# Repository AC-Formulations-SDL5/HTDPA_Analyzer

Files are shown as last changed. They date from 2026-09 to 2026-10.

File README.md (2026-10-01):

<p align="center">
  Self-Driving Laboratory, Acceleration Consortium, University of Toronto
</p>

<p align="center">
  HTDA demonstration
</p>

**[Open the full-resolution HTDA demonstration video](media/HTDA_demo.mp4)**

# HTDPA Analyzer

**Self-Driving Laboratory (SDL5) Formulation**  
**Acceleration Consortium - University of Toronto**

This repository contains the data, software, device designs, laboratory automation, and computational analyses supporting a scientific manuscript submitted to *Digital Discovery*. It is organized as a data-availability and reproducibility package for the high-throughput diffusion/permeation apparatus (HTDPA) and its self-driving laboratory workflow.

## Repository map

| Path | Contents |
| --- | --- |
| [`Example_data/`](Example_data/) | Raw example release datasets in Excel format for formulation and probe conditions. |
| [`Programming/OT_Protocol/`](Programming/OT_Protocol/) | Opentrons protocol used for automated sampling, media replacement, and lid handling. |
| [`Programming/OT_LabWare/`](Programming/OT_LabWare/) | Custom labware definitions used by the OT-2 workflow. |
| [`CAD_files/`](CAD_files/) | STL geometry for the HTDPA cell, reciprocating pump, holders, and related components. |
| [`UI/`](UI/) | Streamlit dashboard for release-profile QC, kinetic fitting, and manuscript summary figures. |
| [`HTDPA_RMSP_Files/`](HTDPA_RMSP_Files/) | RMSP Figure 2 and Figure S2 analyses, source data, generated figures, and post-equilibration validation workflow. |
| [`HTDA_Cell_CFD_Sim/`](HTDA_Cell_CFD_Sim/) | Transient Warp simulation, vorticity sweep, post-processing, notebook, and Ansys Workbench/Fluent files. |
| [`media/`](media/) | Repository presentation assets: quality-optimized and source GIFs, full-resolution video, and SDL5/Acceleration Consortium logo. |

## Reproducibility workflow

The repository is intended to preserve the path from physical design and automated experimentation to analysis and simulation:

1. **Device design:** Inspect the STL files in `CAD_files/` and the CFD/Workbench project in `HTDA_Cell_CFD_Sim/Workbench/`.
2. **Automated experiment:** Review the protocol and labware definitions in `Programming/` before loading a protocol onto an Opentrons system.
3. **Raw data:** Use the workbooks in `Example_data/` as the input data for release analysis. Preserve the original files when creating derived outputs.
4. **Analysis:** Run the dashboard in `UI/` to inspect release profiles, assay QC, kinetic models, apparent permeability, and the Korsmeyer-Peppas exponent.
5. **Flow simulation:** Follow [`HTDA_Cell_CFD_Sim/README.md`](HTDA_Cell_CFD_Sim/README.md) to reproduce the transient and steady-state design-supporting calculations.

## Release-analysis dashboard

The dashboard applies the publication-matched analysis rules documented in [`UI/README_HTDPA_dashboard.md`](UI/README_HTDPA_dashboard.md), including:

- strict-majority LOQ validation for quantitative time points;
- exclusion of negative cumulative-release values;
- common analysis windows for Zero-order, Higuchi, and First-order fits;
- optional start/end control for Korsmeyer-Peppas and Peppas-Sahlin fits;
- replicate-based CV reporting;
- six-panel summary output for release, variability, linearity, model fit, apparent `Kp`, and apparent `n`.

Install the dashboard dependencies and launch it from the dashboard directory:

```powershell
cd UI
python -m pip install -r requirements_htdpa_dashboard.txt
streamlit run htdpa_release_dashboard.py
```

The dashboard accepts the example Excel workbooks and can export analysis summaries as CSV and figures as high-resolution PNG files.

## CFD and flow-design analysis

<p align="center">
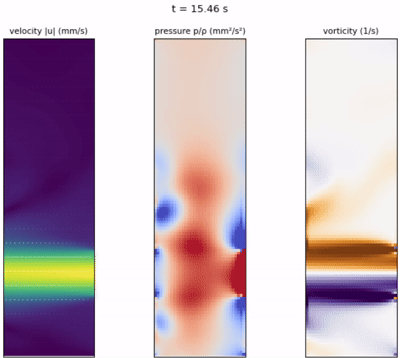
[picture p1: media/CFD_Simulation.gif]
CFD simulation of reciprocating flow
  
</p>

**[Open the CFD simulation video](media/CFD_Simulation.mp4)**

The CFD subproject includes a GPU-capable NVIDIA Warp implementation of a transient 2D reciprocating-flow model, a flow-rate sweep, post-processing scripts, a Jupyter notebook, cached numerical outputs, and an Ansys Workbench/Fluent 3D design study. The precomputed outputs are included so the results can be inspected without rerunning the simulations.

```powershell
cd HTDA_Cell_CFD_Sim
conda env create -f environment.yml
conda activate htda-cfd
python run_all.py
```

See [`HTDA_Cell_CFD_Sim/README.md`](HTDA_Cell_CFD_Sim/README.md) for model parameters, individual stages, hardware requirements, and limitations.

## Data availability and provenance

- Raw example workbooks are retained in `Example_data/`.
- RMSP source data, analysis scripts, figures, and validation outputs are retained in `HTDPA_RMSP_Files/`.
- Analysis and simulation scripts are retained alongside their cached outputs and notebooks.
- CAD and mesh/project files are retained in `CAD_files/` and `HTDA_Cell_CFD_Sim/Workbench/`.
- Protocol and labware definitions are retained in `Programming/`.
- The dashboard changelog is maintained in [`UI/CHANGELOG.md`](UI/CHANGELOG.md).
- Generated figures and exported summaries should be treated as derived data and should retain a clear link to their input workbook and analysis settings.

This repository is a research artifact for the associated manuscript. Experimental interpretation should use the manuscript and the documented analysis assumptions together with the files here. The CFD model is design-supporting and includes the limitations described in its subproject README; it is not a substitute for experimental validation.

## Citation

Please cite the associated *Digital Discovery* manuscript and identify the repository revision used for analysis. A formal citation record can be added here when the manuscript and repository release receive their final bibliographic information.

## Contact

**Self-Driving Laboratory (SDL5) Formulation**  
Acceleration Consortium  
University of Toronto

- Frantz Le Devedec (frantz.ledevedec@utoronto.ca)
- Mahdi Rastegardoost (m.rastegardoost@utoronto.ca)
- Zeqing Bao (zeqing.bao@utoronto.ca)

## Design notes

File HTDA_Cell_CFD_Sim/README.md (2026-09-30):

# HTDA Cell CFD Simulation

Supporting CFD files for the HTD/PA (high-throughput diffusion / permeation apparatus) receptor-cell design.

The folder has two parts:

1. **Transient 2D reciprocating-flow model (Python / NVIDIA Warp).** A single receptor cell (a rectangular chamber with inlet and outlet ports) is driven by the bipolar square-wave flow of the multichannel reciprocating pump. The model gives velocity, pressure and vorticity fields over one reciprocation cycle, plus peak and RMS vorticity as a function of flow-rate amplitude.
2. **Steady-state 3D design study (Ansys Workbench / Fluent 2025 R2).** This is the project used to compare candidate cell geometries (velocity contours, streamlines, pressure).

For the scientific background and how the results were used, see [Explanation.md](Explanation.md).

---

## Contents

| File / folder | Description |
|---|---|
| `warp_reciprocating_flow.py` | Solver: geometry, physics parameters, Taylor–Hood Q2–Q1 Navier–Stokes, `run()` (single flow rate) and `run_sweep()` (flow-rate sweep) |
| `plot_reciprocating_flow.py` | Post-processing: snapshot-grid figure and vorticity-vs-flow-rate figure |
| `build_artifact.py` | Builds the standalone interactive HTML frame viewer |
| `run_all.py` | **One-command runner** for all stages (simulation → sweep → figures → viewer) |
| `reciprocating_flow_CFD.ipynb` | Notebook version: explanation, run, and plots |
| `environment.yml` | Conda environment with the required libraries |
| `reciprocating_flow_results.npz` | *Output:* ~60 frames over one period at Q = 40 mL/min (u, p, vorticity) |
| `vorticity_sweep_results.npz` | *Output:* sweep of Q = 5–50 mL/min (peak/RMS vorticity, peak velocity, pressure, Re) |
| `snapshot_grid.png` | *Output:* velocity / pressure / vorticity at 4 key phases of the cycle |
| `vorticity_vs_flowrate.png` | *Output:* vorticity and vorticity/Q vs. flow-rate amplitude |
| `reciprocating_flow_viewer.html` | *Output:* self-contained interactive viewer (open in any browser) |
| `Workbench/` | Ansys Workbench project (`HTDA_Cell_Design.wbpj` + `_files/`: geometry, mesh, Fluent case/data, exported images) |

The precomputed outputs are included, so the figures and viewer can be inspected without rerunning anything.

---

## Requirements

- **Python 3.10 or 3.11** (tested with 3.11 and warp-lang 1.13.0)
- **NVIDIA GPU with a recent CUDA driver** (recommended). Warp also runs on the CPU if no GPU is found, but it is much slower.
- Libraries: `numpy`, `matplotlib`, `warp-lang`, and `jupyterlab`/`ipykernel` for the notebook (all listed in [environment.yml](environment.yml))
- *Optional:* Ansys Workbench 2025 R2 or newer to open the `Workbench/` project

## Installation

With conda (recommended):

```bash
conda env create -f environment.yml
conda activate htda-cfd
```

With pip only:

```bash
pip install numpy matplotlib warp-lang jupyterlab ipykernel
```

To check the install (prints the CUDA device Warp found):

```bash
python -c "import warp as wp; wp.init()"
```

---

## Running

Run every command from inside this folder, because outputs are written next to the scripts.

### Option A: one command

```bash
python run_all.py                    # reuse cached .npz files, regenerate figures + viewer
python run_all.py --force            # rerun both simulations from scratch
```

Individual stages:

```bash
python run_all.py --stage sim        --force --q 40     # single transient run at Q = 40 mL/min
python run_all.py --stage sweep      --force --q-min 5 --q-max 50 --n-q 10
python run_all.py --stage figures                       # PNG figures from the .npz files
python run_all.py --stage viewer                        # interactive HTML viewer
```

Approximate runtimes on a laptop RTX GPU: single run ~2 min; sweep (10 flow rates) ~15–20 min.

### Option B: notebook

Open `reciprocating_flow_CFD.ipynb` in Jupyter or VS Code, select the `htda-cfd` kernel, and run all cells. The notebook uses the cached `.npz` files if they exist. Delete them to force a new simulation.

### Option C: individual scripts

```bash
python warp_reciprocating_flow.py    # single run -> reciprocating_flow_results.npz
python plot_reciprocating_flow.py    # figures (needs both .npz files)
python build_artifact.py             # interactive HTML viewer
```

---

## Model summary

| Parameter | Value | Variable in `warp_reciprocating_flow.py` |
|---|---|---|
| Chamber (W × H) | 7.75 × 27 mm | `RECT_W`, `RECT_H` |
| Port diameter | 4 mm, centred 7 mm above the chamber floor | `PIPE_D`, `Y_C` |
| Inlet stub length | 12 mm (3 × D, keeps the boundary condition away from the junction) | `STUB_LEN` |
| Through-plane depth (2D → flow-rate conversion) | 4 mm | `DEPTH` |
| Fluid | water, ν = 1.0 mm²/s | `NU` |
| Flow forcing | bipolar square wave, amplitude 40 mL/min, period 9 s | `Q_AMP_ML_MIN`, `PERIOD` |
| Grid / time step | 130 × 112 cells (masked `Grid2D`), Δt = 0.009 s | `NX`, `NY`, `DT` |
| Simulated duration | 2 periods; statistics and frames are taken from the 2nd period | `N_PERIODS` |

- **Units:** mm and s throughout. Pressure is kinematic (p/ρ, mm²/s²). Multiply by ρ = 1000 kg/m³ and by 10⁻⁶ to get Pa.
- **Method:** Taylor–Hood Q2/Q1 elements, implicit viscosity, semi-Lagrangian advection, hard velocity-Dirichlet BCs (parabolic profile at the two port tips, no-slip elsewhere), preconditioned CG saddle-point solve.
- **Sweep statistics:** the sweep excludes samples within 15 % of each flow reversal, so the reported vorticity reflects the fully developed flow and not the reversal transient.
- **Changing the device:** edit the constants at the top of `warp_reciprocating_flow.py`, then run `python run_all.py --force`. Velocity, pressure and vorticity magnitudes scale roughly as 1/`DEPTH`.

## Limitations

This is a simplified 2D planar idealization, and the results are design-supporting predictions. They have not been validated experimentally. The square-wave forcing is instantaneous, so it produces a real, sharp inertial pressure transient at each reversal; this is not a numerical artifact.

## Ansys Workbench project

Open `Workbench/HTDA_Cell_Design.wbpj` in Ansys Workbench 2025 R2 or newer, and keep the `HTDA_Cell_Design_files/` folder next to it. Exported contour, streamline and vector images are in `Workbench/HTDA_Cell_Design_files/user_files/`.

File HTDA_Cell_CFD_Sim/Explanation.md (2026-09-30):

## 2.1 HTD/PA design
The HTD/PA was designed as a modular, automation-compatible flow-cell platform for standardized diffusion/permeation experiments (Fig. 2C). The flow-cell module was designed in Fusion 360 (Autodesk, USA) and fabricated using transparent photopolymer resin (Clear Resin V4.1, Formlabs) on a Form 3L stereolithography printer. The transparent construction enables direct visualization of liquid circulation, bubble formation, membrane positioning, and receptor-chamber filling during operation. Each HTD/PA module consists of 4-pairs of dual flow-cells, with each cell set comprising a donor compartment accommodating an interchangeable commercial permeable insert (donor - sample) and a receptor compartment, connected to a closed-loop circulation system. Standard Luer-lock connectors were incorporated at the inlet and outlet ports of each channels to facilitate connection to silicone tubing, a customed inline heat exchanger, flow sensors, and a multichannel reciprocating pump (Section 2.2). The modular architecture enables replacement of donor inserts with different geometry while maintaining a standardized receptor geometry (Flow cell I.D 2.5 cm) across experiments (Fig. 2D). A custom 3D-printed lid secures the donor inserts, minimizes dead volume above the receptor chamber, and reduce evaporation during long-term experiments. A self-sealing cross-slit silicone septum integrated into the lid allows repeated robotic pipette access for automated release sampling without exposing the receptor compartment to the environment. The HTD/PA cell geometry and mechanical design were evaluated through computational fluid dynamics to identify a design that achieves adequate receptor-side mixing across all cells of the apparatus. Steady-state CFD velocity contours of flow through the HTD/PA block cells (Ansys Fluent 2025 R2; Fig. 2E) were used to compare candidate cell geometries and select an optimized design. For the optimized cell, shear rate and vorticity were evaluated as a function of inlet flow rate (Fig. 2F); both increased with flow rate, with vorticity rising from ~3.2 s⁻¹ at 10 mL/min to ~16 s⁻¹ at 40 mL/min. As a measure of local shear and rotational flow intensity, vorticity was adopted as a practical, quantitative proxy for convective mixing within the receptor chamber. Because the multichannel reciprocating pump (Section 2.2) delivers a bipolar square-wave flow-rate waveform rather than steady unidirectional flow, mixing under this operating condition was further assessed with a transient, simplified 2D model of a single receptor cell (a rectangular chamber with inlet/outlet ports positioned as in the cup-shaped receptor geometry, with the membrane and donor compartment above), solved in Python with the NVIDIA Warp finite-element framework by imposing the bipolar flow-rate waveform at the two ports. Figure 2G shows the resulting vorticity and pressure contours at representative time points across a reciprocation cycle, capturing jet formation, flow reversal, and the associated shear layers. Peak vorticity normalized by flow-rate amplitude (Fig. 2H) rises sharply between 5 and ~20 mL/min before plateauing at higher amplitudes, indicating diminishing mixing gains beyond this threshold; this relationship was used to set the minimum pump flow-rate amplitude required for adequate receptor-side mixing without operating at unnecessarily high flow. As with the steady-state Ansys analysis, these results were used as design-supporting predictions rather than an experimentally validated description of the hydrodynamic environment.

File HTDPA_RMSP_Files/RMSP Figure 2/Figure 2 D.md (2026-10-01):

# SLF3X peak-to-peak flow versus RPM

Generate the figure with the standalone [Python script](SLF3X_peak_to_peak_vs_RPM.py).

Peak-to-peak flow versus pump speed

## Installation

Requires Python 3.9 or newer, NumPy, pandas, and Matplotlib:

```bash
python3 -m pip install numpy pandas matplotlib
```

## Input files

Place these CSV files beside the script:

| Pump speed (RPM) | Source file |
| ---: | --- |
| 5 | `HTDPA_5RPM_30oC_1H.csv` |
| 10 | `HTDPA_10RPM_30oC_1H.csv` |
| 15 | `HTDPA_15RPM_30oC_1H.csv` |
| 20 | `HTDPA_20RPM_30oC_1H.csv` |
| 25 | `HTDPA_25rpm_30oC_1H.csv` |
| 30 | `HTDPA_30rpm_30oC_1.5H.csv` |

The script reads numeric flow columns `s1_flow_ml_min` through `s4_flow_ml_min`. At 30 RPM, sensor 2 is excluded because of the sensor issue documented in the combined-figure script; its column is unused. The source data contain one-second averaged readings. No Excel workbooks, backup files, existing images, or other project scripts are needed.

## Usage

From the script folder:

```bash
python3 SLF3X_peak_to_peak_vs_RPM.py
```

The output is `SLF3X_peak_to_peak_vs_RPM.png`, saved beside the script. Running the default command overwrites an existing image with that name. Source CSV files are unchanged.

To specify other locations:

```bash
python3 SLF3X_peak_to_peak_vs_RPM.py --data-dir "/path/to/data" --output "/path/to/figure.png"
```

The output directory must already exist. Show command-line help with:

```bash
python3 SLF3X_peak_to_peak_vs_RPM.py --help
```

## Calculations

### Flow recalibration

Each recorded flow value is corrected as follows:

```text
corrected flow = recorded flow / old embedded factor × gravimetric factor
```

| Sensor | Old embedded factor | Gravimetric factor |
| --- | ---: | ---: |
| S1 | 4.4 | 4.508343 |
| S2 | 4.2 | 4.474666 |
| S3 | 2.0 | 2.320488 |
| S4 | 3.0 | 3.340179 |

These constants assume the calibration basis of the supplied CSV files. Using already recalibrated values would apply the correction again.

### Plateau detection

For each sensor, the deadband is 15% of the 90th percentile of absolute finite flow values. Contiguous positive and negative runs outside that deadband must contain at least three samples.

A positive lobe plateau is the mean of values at or above that lobe's median. A negative lobe plateau is the mean of values at or below its median. Q+ and Q− are the respective means across detected lobe plateaus.

### Peak-to-peak flow and error bars

Each sensor's peak-to-peak flow is **Q+ − Q−**, in mL/min. It is a plateau-based measure, rather than the raw maximum minus minimum.

Each bar is the mean across four sensors at 5–25 RPM, and three sensors (S1, S3, S4) at 30 RPM. Error bars show ±1 sample standard deviation across sensors (`ddof=1`). Labels show the mean and coefficient of variation:

```text
CV (%) = 100 × sample SD / |mean|
```

## Output and validation

The output is a 19,200 × 10,800 pixel PNG rendered at 1200 DPI (16 × 9 inches). The script generates only the peak-to-peak figure.

The original 300 DPI version was checked against the existing figure using the supplied CSV files and reproduced it pixel for pixel. The script now renders the same plot at 1200 DPI. Different Matplotlib versions or fonts may affect rendering.

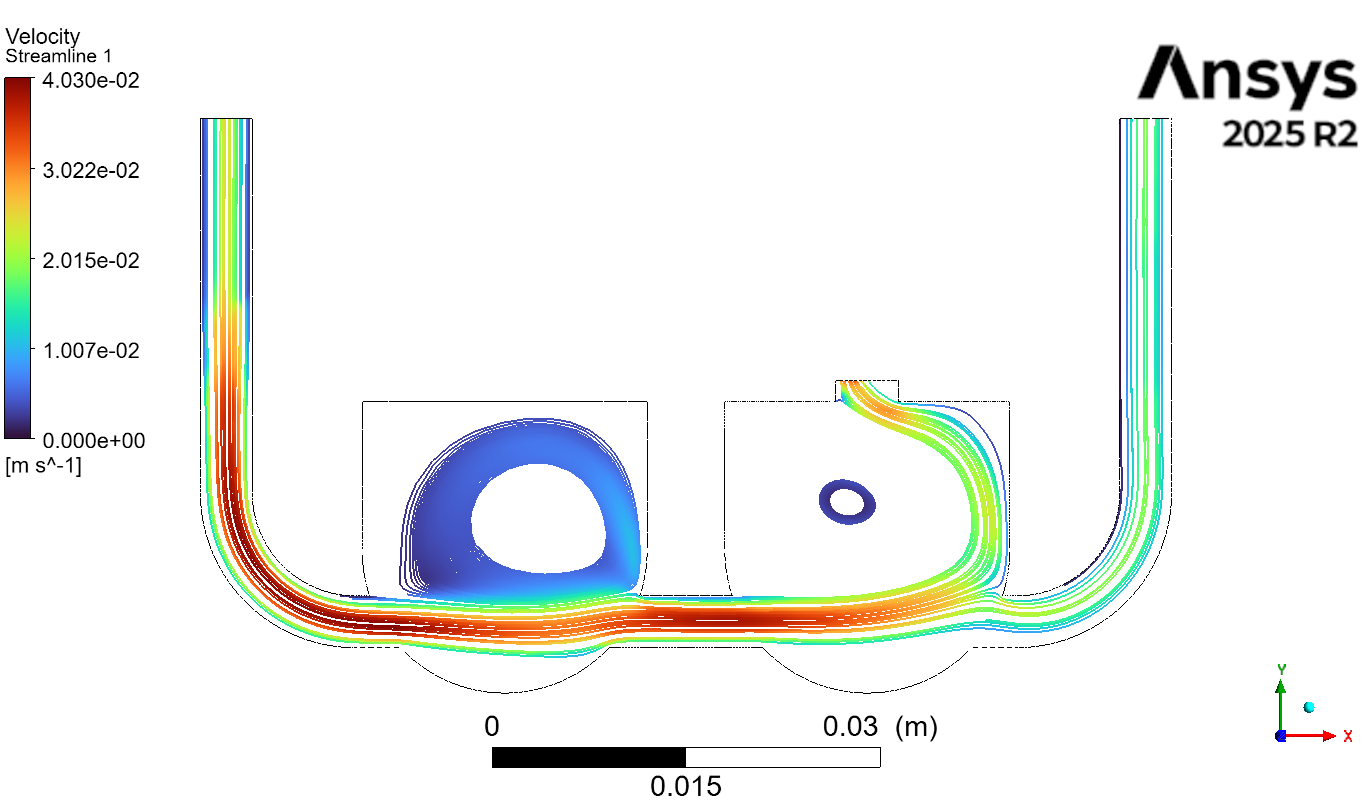
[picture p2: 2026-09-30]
HTDA_Cell_CFD_Sim/Workbench/HTDA_Cell_Design_files/user_files/HTDA_Cell_Design_streamline2.png

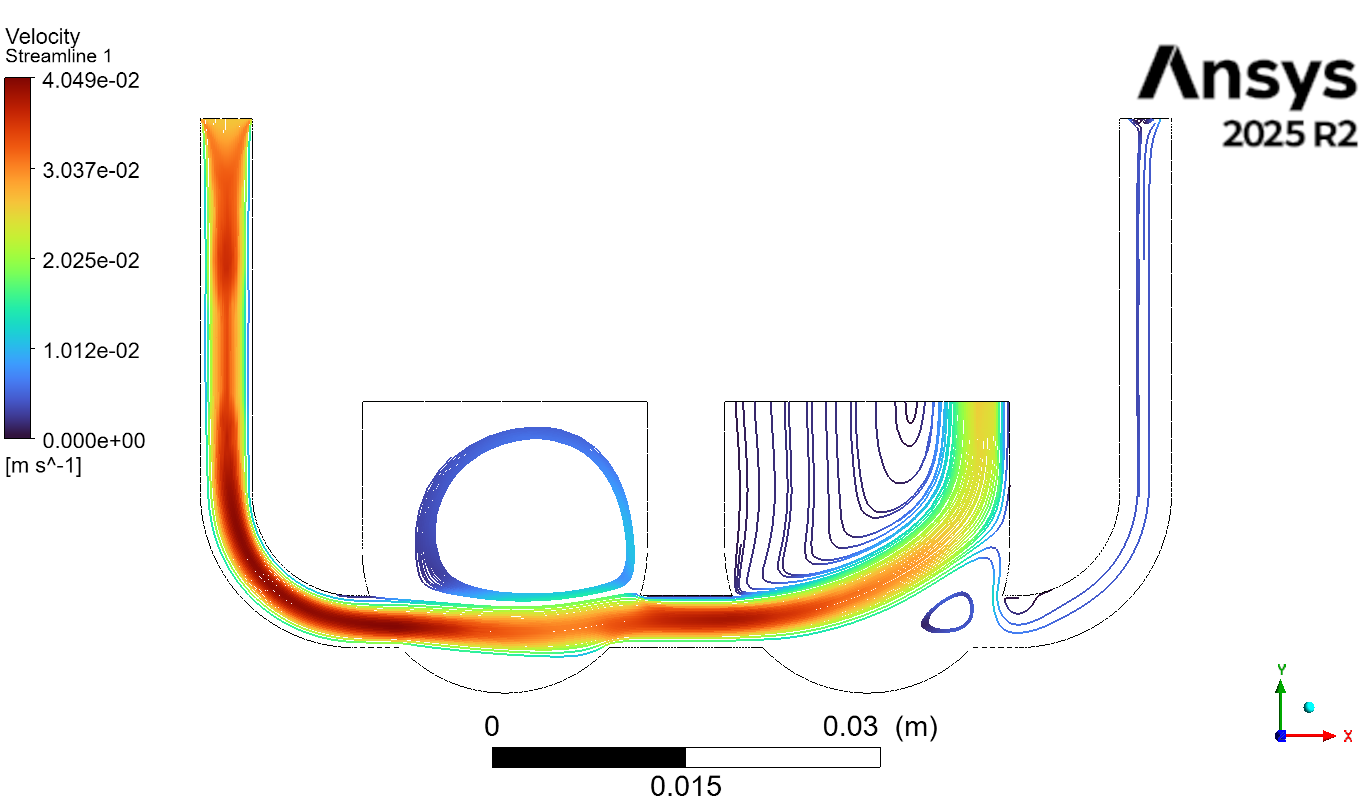
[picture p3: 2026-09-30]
HTDA_Cell_CFD_Sim/Workbench/HTDA_Cell_Design_files/user_files/HTDA_Cell_Design_streamline.png

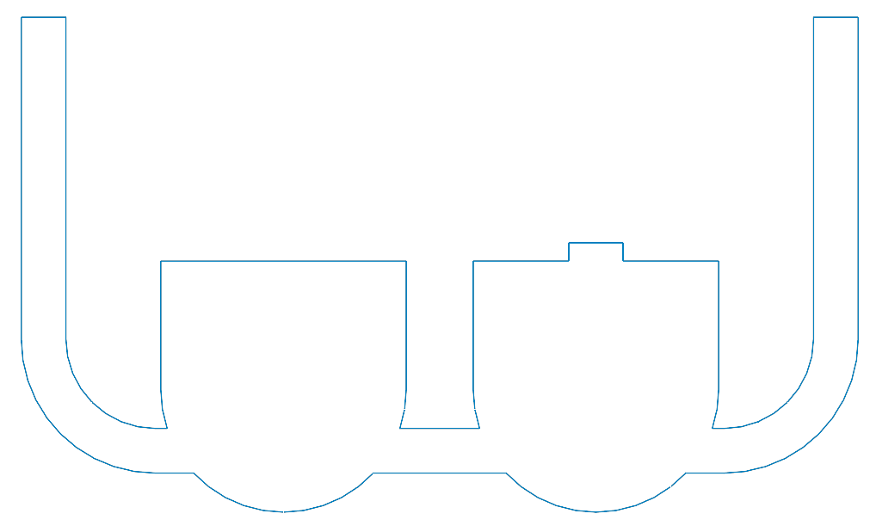
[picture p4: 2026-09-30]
HTDA_Cell_CFD_Sim/Workbench/HTDA_Cell_Design_files/user_files/geometry_2d.png

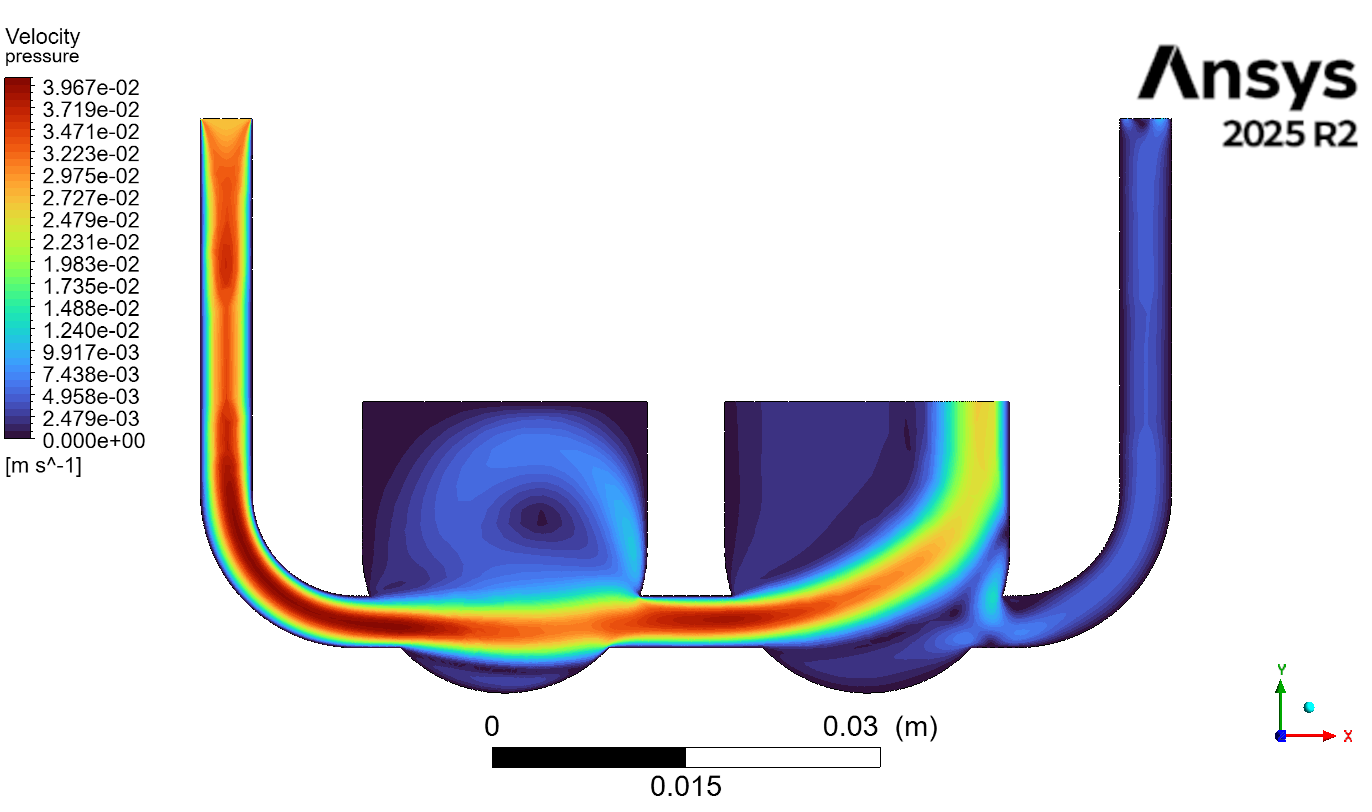
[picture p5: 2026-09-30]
HTDA_Cell_CFD_Sim/Workbench/HTDA_Cell_Design_files/user_files/HTDA_Cell_Design_velocity.png

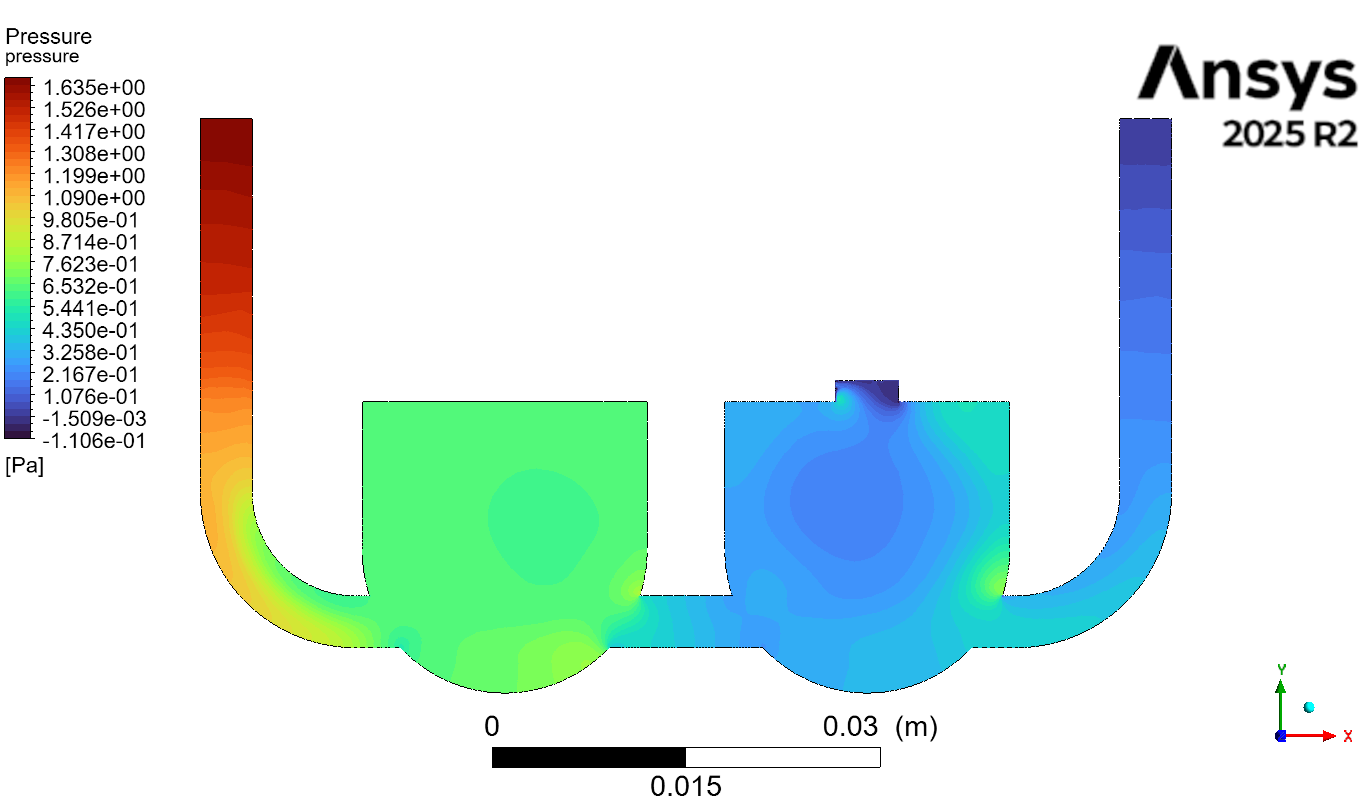
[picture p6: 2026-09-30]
HTDA_Cell_CFD_Sim/Workbench/HTDA_Cell_Design_files/user_files/HTDA_Cell_Design_pressure2.png

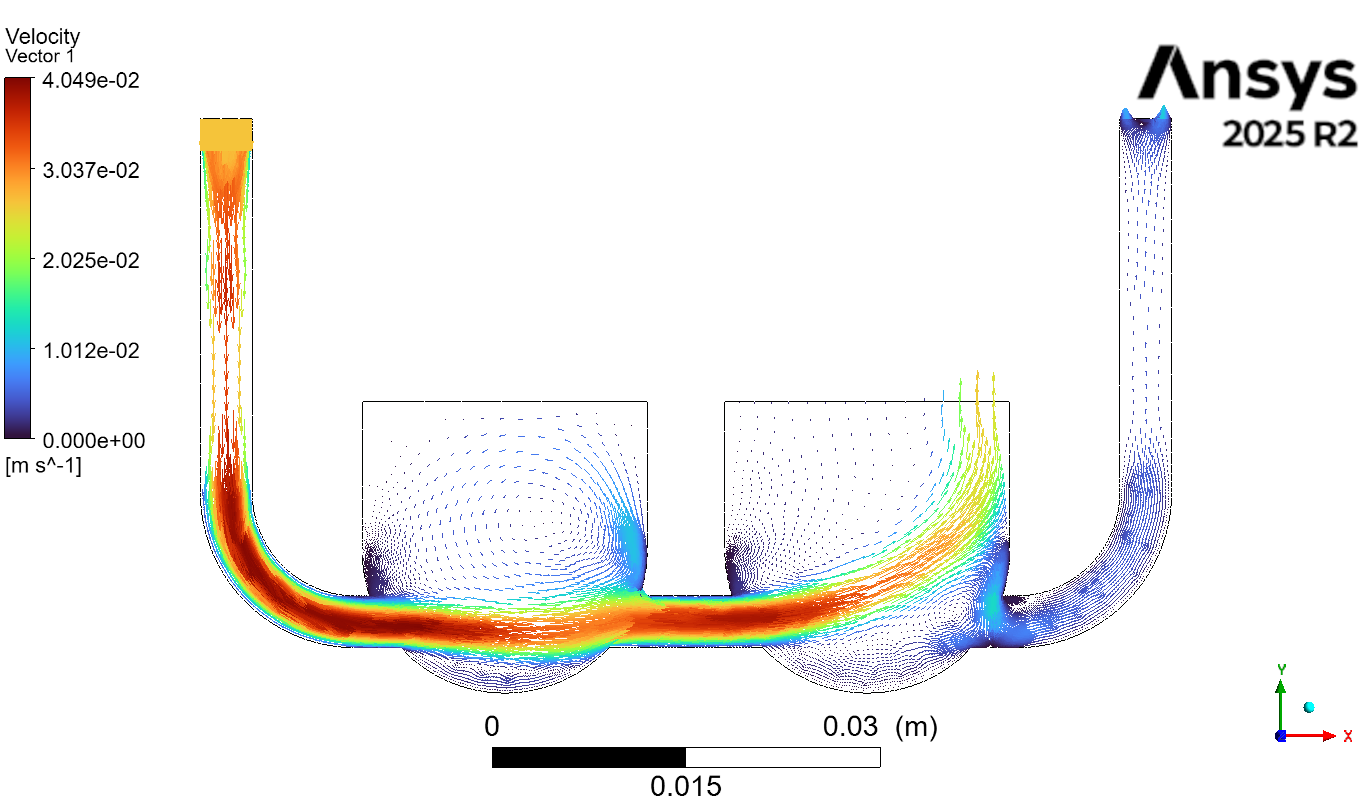
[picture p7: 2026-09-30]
HTDA_Cell_CFD_Sim/Workbench/HTDA_Cell_Design_files/user_files/HTDA_Cell_Design_vector.png

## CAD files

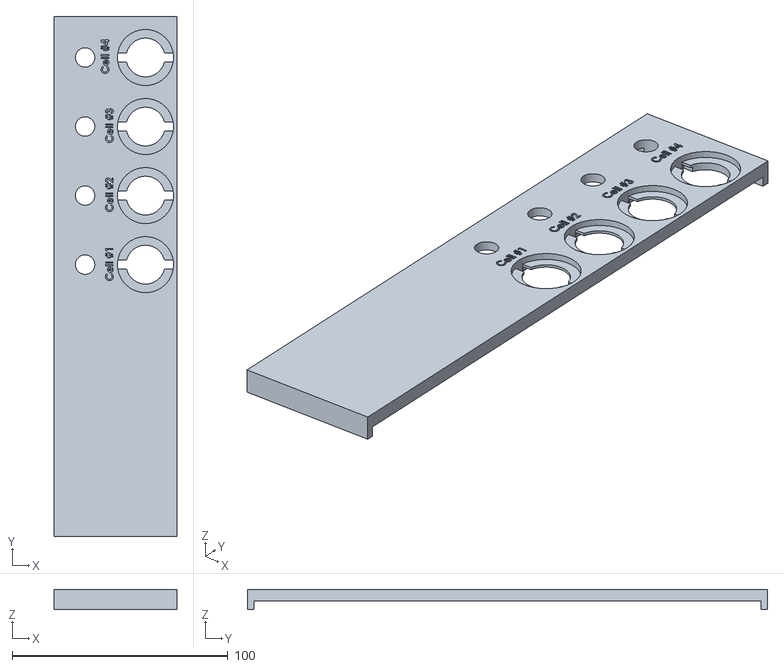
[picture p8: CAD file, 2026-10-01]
CAD_files/HTDPA_Lid.STL
56.8 x 241.0 x 9.50

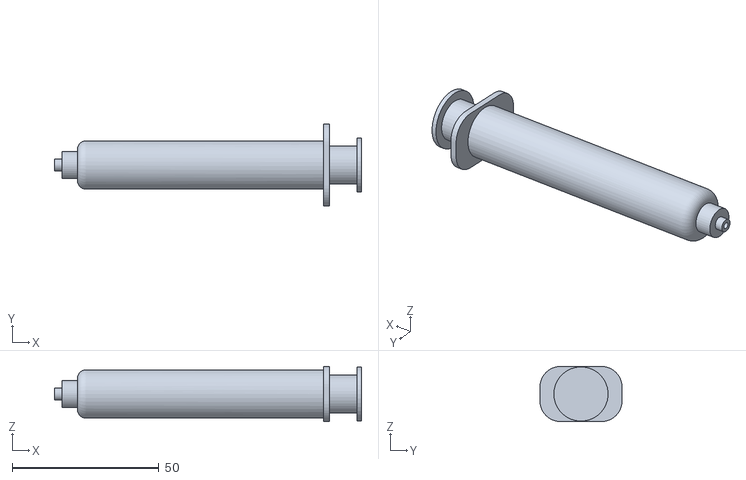
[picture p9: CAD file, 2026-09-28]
CAD_files/RMSP - OT-2 Reference Model Updated-1 Stripped __Model-1 Reciprocating PUmp-1 Pump_v3-2-1.STL
104.7 x 28.0 x 18.8

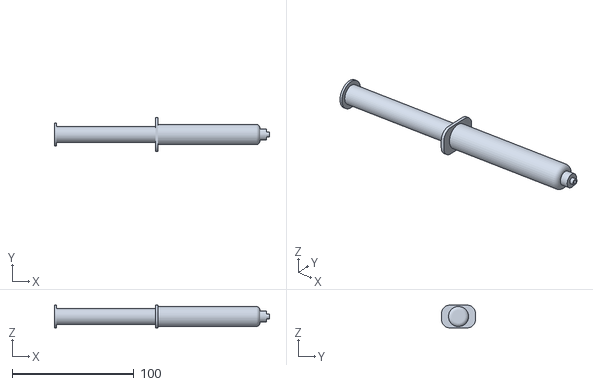
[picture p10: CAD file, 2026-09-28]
CAD_files/RMSP - OT-2 Reference Model Updated-1 Stripped __Model-1 Reciprocating PUmp-1 Pump_v3-8-1.STL
176.7 x 28.0 x 18.8

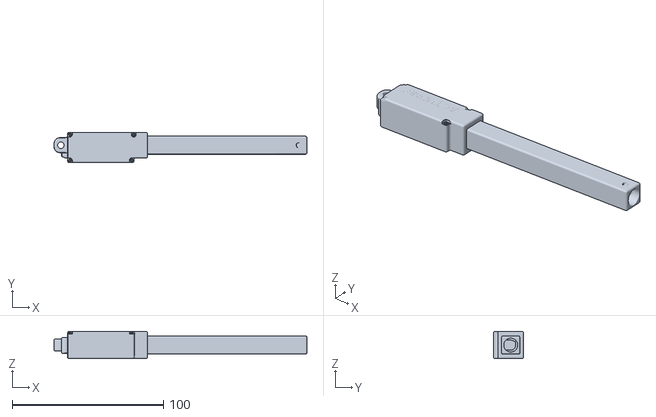
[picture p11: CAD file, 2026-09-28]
CAD_files/RMSP - OT-2 Reference Model Updated-1 Stripped __ng PUmp-1 l16_100mm-1 L16_100MM_BODY_A-1.STL
167.4 x 20.0 x 18.1

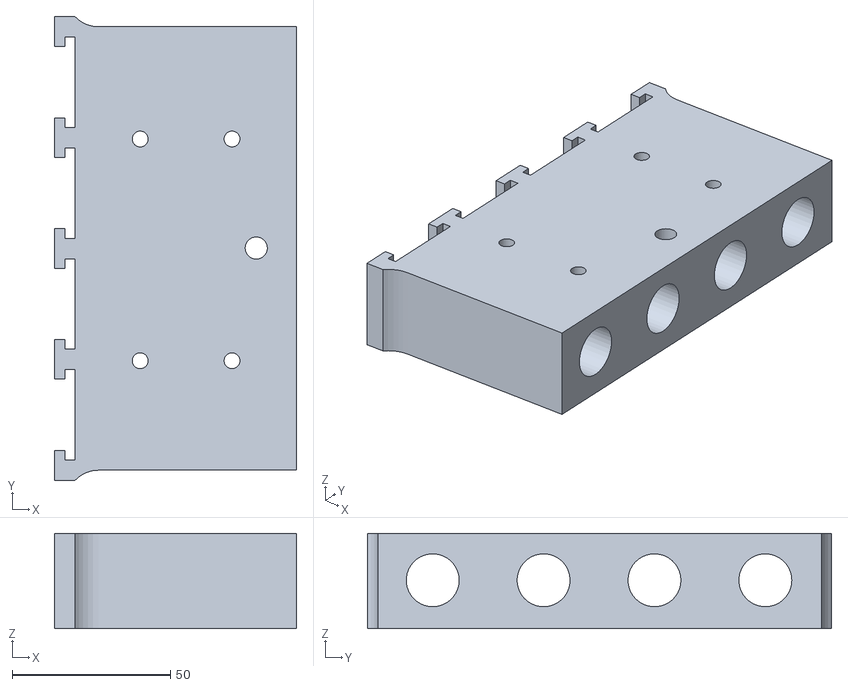
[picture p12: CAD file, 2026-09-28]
CAD_files/RMSP - OT-2 Reference Model Updated-1 Stripped __odel-1 Reciprocating PUmp-1 Pump_v3-10-1.STL
76.5 x 146.5 x 30.0

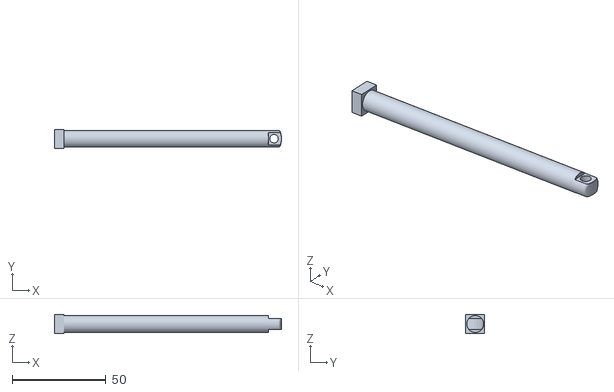
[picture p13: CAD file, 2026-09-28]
CAD_files/RMSP - OT-2 Reference Model Updated-1 Stripped __ng PUmp-1 l16_100mm-1 L16_100MM_LIFT_A-1.STL
121.0 x 9.90 x 10.2

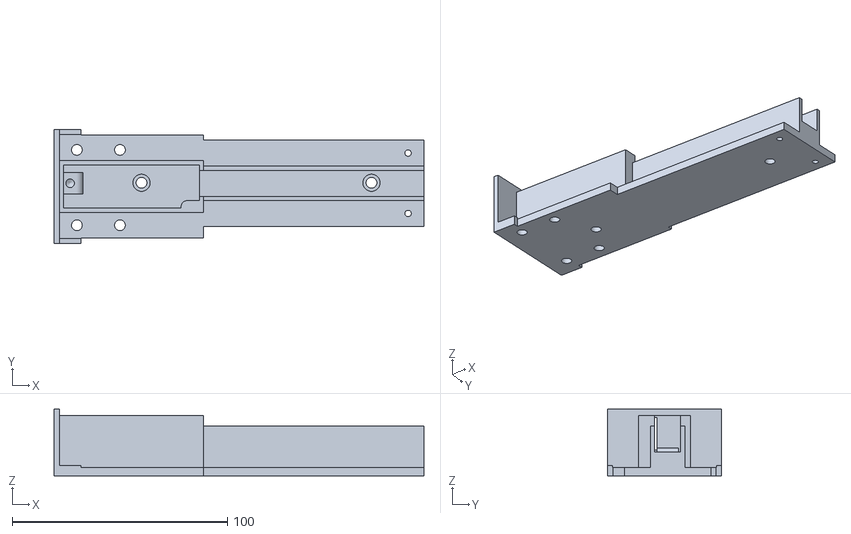
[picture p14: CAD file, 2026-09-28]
CAD_files/RMSP - OT-2 Reference Model Updated-1 Stripped __-1 Reciprocating PUmp-1 Act_housing_V2-1.STL
171.9 x 53.0 x 31.0

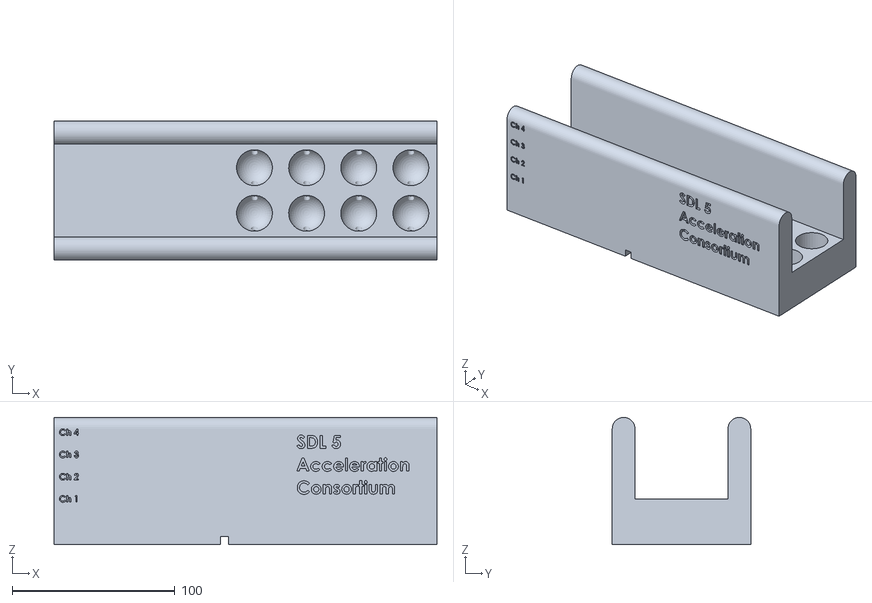
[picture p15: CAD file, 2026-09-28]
CAD_files/HTDA_4C.STL
235.0 x 85.0 x 78.0

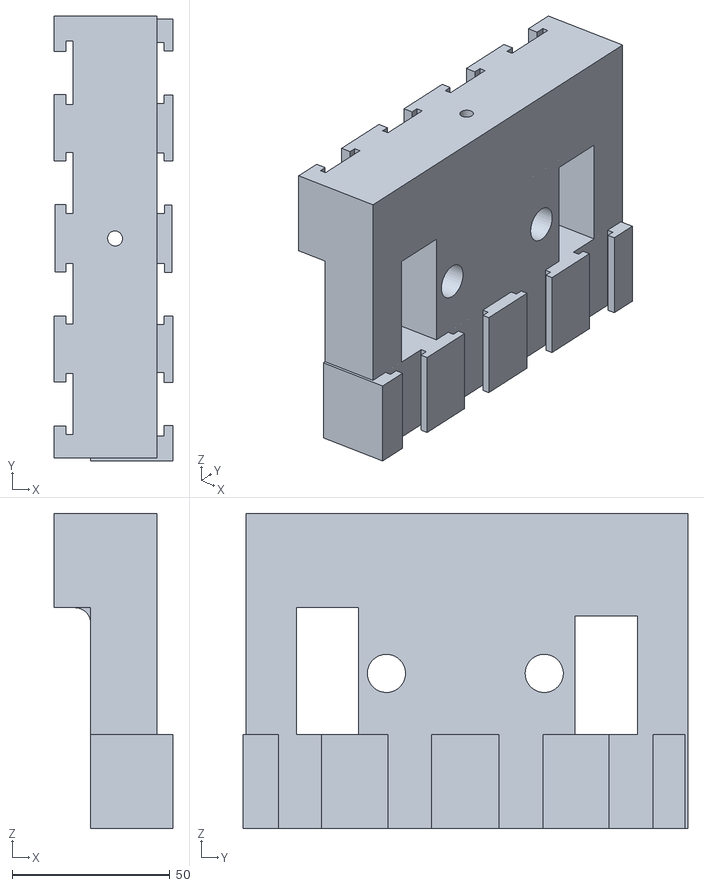
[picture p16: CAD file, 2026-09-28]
CAD_files/RMSP - OT-2 Reference Model Updated-1 Stripped __Model-1 Reciprocating PUmp-1 Pump_v3-9-1.STL
37.6 x 141.0 x 99.9

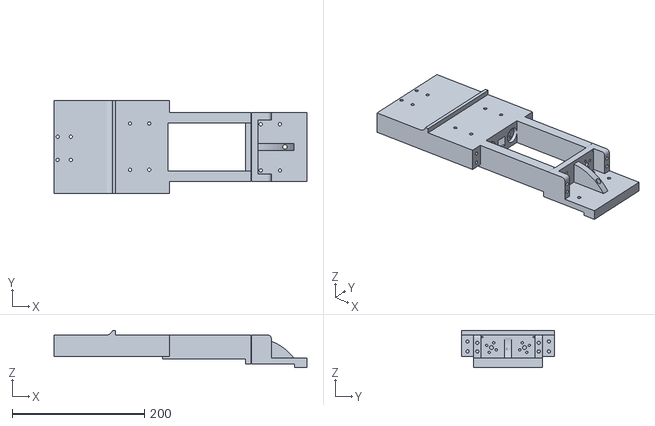
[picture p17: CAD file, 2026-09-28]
CAD_files/RMSP - OT-2 Reference Model Updated-1 Stripped __se_plus_holder_V2-1 Syringe_housing_V2-1.STL
382.8 x 140.1 x 56.0

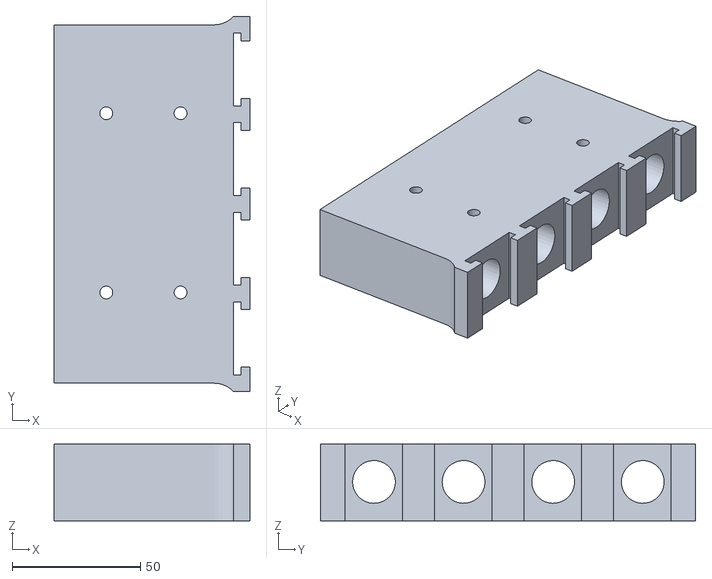
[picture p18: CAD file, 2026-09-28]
CAD_files/RMSP - OT-2 Reference Model Updated-1 Stripped __Model-1 Reciprocating PUmp-1 Pump_v3-5-1.STL
76.5 x 146.5 x 30.0

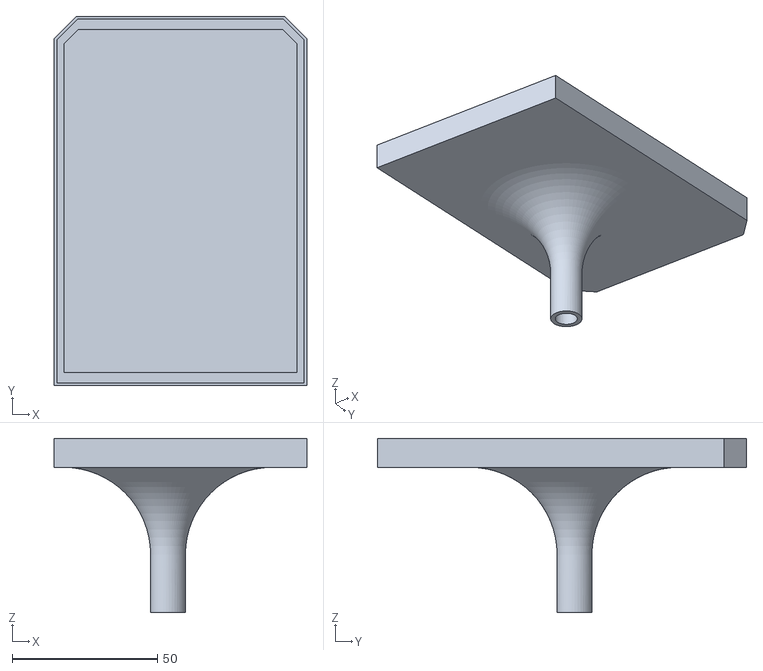
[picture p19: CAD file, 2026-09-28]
CAD_files/wellplate_lid.STL
87.0 x 127.0 x 60.0

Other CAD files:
CAD_files/RMSP - OT-2 Reference Model Updated-1 Stripped __Model-1 Reciprocating PUmp-1 Pump_v3-1-1.STL
CAD_files/RMSP - OT-2 Reference Model Updated-1 Stripped __Model-1 Reciprocating PUmp-1 Pump_v3-0-1.STL
CAD_files/RMSP - OT-2 Reference Model Updated-1 Stripped __Model-1 Reciprocating PUmp-1 Pump_v3-4-1.STL
CAD_files/RMSP - OT-2 Reference Model Updated-1 Stripped __Model-1 Reciprocating PUmp-1 Pump_v3-7-1.STL
CAD_files/RMSP - OT-2 Reference Model Updated-1 Stripped __Model-1 Reciprocating PUmp-1 Pump_v3-3-1.STL
CAD_files/RMSP - OT-2 Reference Model Updated-1 Stripped __Model-1 Reciprocating PUmp-1 Pump_v3-6-1.STL

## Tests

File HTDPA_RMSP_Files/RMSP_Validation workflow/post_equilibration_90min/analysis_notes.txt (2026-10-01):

Post-equilibration descriptive statistics
Source: 20260916_1um_MBP23_30rpm_CH1_CH3_CH4_corrected.csv
Window: elapsed time >=90 min, relative to first recorded timestamp.
Actual selected range: 90.002650–436.082117 min.
Samples per channel: 20761. Channels: CH1, CH3, CH4; CH2 is absent.
Data are already corrected; no additional correction factors applied.
No missing entries; timestamps strictly increasing. Maximum sampling interval: 1.057 s.
90 minutes is a user-selected cutoff, not a fitted or verified equilibration time.

Cycle detection: negative-to-positive transitions with hysteresis at 20% of
median nonzero absolute flow (thresholds in mL/min: {'CH1': np.float64(8.008000000000001), 'CH3': np.float64(8.76), 'CH4': np.float64(8.65)}).
Each cycle extends from one positive threshold crossing to the next.
Only fully bounded cycles starting >=90 min are included. Leading/trailing
partial cycles are excluded. At least 3 samples per polarity are required.
Q+ = mean of upper half (>=median) of positive phase samples above threshold.
Q− = mean of lower half (<=median) of negative phase samples below -threshold.
P–P = Q+ − Q−; symmetry = Q+/|Q−|, calculated per cycle before summarizing.
This explicit plateau estimator is comparable in concept to the S2 upper/lower
half method but uses hysteresis to avoid transition noise.
Upper/lower decile estimates are also supplied, matching the decile concept
in the existing plotting script. Its imported helper is absent, so exact
reproduction of its unpublished cycle algorithm is not claimed.
Raw peak-to-peak = per-cycle max minus min; distinct from plateau P–P.
Volumes integrate clipped positive/negative flow over each cycle with the
trapezoidal rule; pull volume is a positive magnitude.

SD is sample SD (ddof=1); CV=100*SD/abs(mean). Temperature CV uses Celsius,
matching the prior figure; this CV depends on the temperature scale.
Temperature/sample-flow statistics use every selected sample, including
transitions. Flow waveform SD/CV is distinct from cycle-to-cycle plateau CV;
signed-flow CV can be large because its mean is near zero.
Inter-channel statistics use the three channel means (n=3), not pooled samples.
Temperature differences use paired simultaneous samples.
30-minute windows assign cycles by cycle start, with a shorter final window.
No inter-day CV is available from this single recording. Repeated time samples
and cycles are not independent biological/experimental replicates; no naive
confidence intervals or significance tests are reported.

Channel summary:
channel  n_samples  n_cycles  temperature_mean_C  temperature_sd_C  temperature_cv_percent  Q_plus_mean  Q_plus_sd  Q_plus_cv_percent  Q_minus_mean  Q_minus_sd  Q_minus_cv_percent  P_to_P_mean  P_to_P_sd  P_to_P_cv_percent  symmetry_mean  symmetry_sd  symmetry_cv_percent  period_s_mean  period_s_sd  period_s_cv_percent
    CH1      20761       848             29.1045            0.6349                  2.1814      40.4458     1.2396             3.0648      -42.7489      0.6363              1.4884      83.1947     1.6356             1.9659         0.9461       0.0258               2.7254        24.4526       0.4972               2.0332
    CH3      20761       848             28.2498            0.5802                  2.0537      43.8108     0.5403             1.2333      -49.9699      0.5801              1.1608      93.7807     1.0906             1.1629         0.8767       0.0048               0.5518        24.4526       0.4972               2.0332
    CH4      20761       848             27.2620            0.5141                  1.8857      43.3686     0.9165             2.1132      -46.2191      0.7579              1.6398      89.5877     1.6483             1.8399         0.9383       0.0075               0.7992        24.4526       0.4979               2.0362

Temperature differences:
comparison unit     n   mean     sd  cv_percent  median    min    q25    q75    max
 CH1 − CH3   °C 20761 0.8547 0.1425     16.6741  0.8000 0.3000 0.7000 1.0000 1.3000
 CH1 − CH4   °C 20761 1.8425 0.1923     10.4385  1.8000 1.4000 1.7000 2.0000 2.4000
 CH3 − CH4   °C 20761 0.9878 0.1045     10.5838  1.0000 0.7000 0.9000 1.1000 1.5000

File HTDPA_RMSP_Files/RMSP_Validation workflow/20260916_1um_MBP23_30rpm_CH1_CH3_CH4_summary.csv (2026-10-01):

channel | correction_factor | n_cycles | q_plus_mean | q_plus_sd | q_plus_cv_pct | q_minus_mean | q_minus_sd | q_minus_cv_pct | p_to_p_mean | q_ratio_mean | temperature_mean_c | temperature_sd_c | temperature_cv_pct
CH1 | 2.2 | 1892 | 41.06643210235534 | 1.9360607921485002 | 4.714460675139729 | -43.131548556430445 | 1.202631268902662 | 2.78828678578331 | 84.19798065878578 | 0.9521205121728185 | 29.136571675302246 | 0.6397711532963468 | 2.1957667512360484
CH3 | 2.0 | 1892 | 44.192074882995314 | 0.808460008227152 | 1.829423059151811 | -50.20121808386039 | 0.8256538214575876 | 1.6446888202560048 | 94.39329296685571 | 0.8802988566766071 | 28.273298791019002 | 0.5809766918785636 | 2.0548599446171116
CH4 | 2.5 | 1892 | 43.945380680108336 | 1.387984539434684 | 3.1584310295051066 | -46.55218471733278 | 1.0691064968378068 | 2.296576419193805 | 90.49756539744112 | 0.9440025413833295 | 27.285539723661483 | 0.5154434068565082 | 1.88907169173394

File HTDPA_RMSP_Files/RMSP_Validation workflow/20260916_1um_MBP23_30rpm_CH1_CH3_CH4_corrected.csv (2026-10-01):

time_s | s1_flow_ml_min | s1_temp_c | s3_flow_ml_min | s3_temp_c | s4_flow_ml_min | s4_temp_c
0.005 | 0.0 | 24.8 | 0.0 | 24.3 | 0.0 | 23.6
1.005 | 0.0 | 24.9 | 0.0 | 24.4 | 0.0 | 23.6
2.005 | 0.0 | 24.9 | 0.0 | 24.5 | 0.0 | 23.7
3.005 | 0.0 | 25.0 | 0.0 | 24.5 | 0.0 | 23.7
4.005 | 0.44000000000000006 | 24.9 | 0.0 | 24.5 | 0.0 | 23.7
5.036 | 0.66 | 24.5 | 1.8 | 24.3 | 1.75 | 23.5
6.036 | 23.1 | 23.6 | 25.0 | 22.8 | 29.0 | 22.2
7.036 | 52.58 | 21.7 | 53.4 | 21.3 | 53.5 | 21.1
8.036 | 49.50000000000001 | 21.4 | 50.6 | 21.0 | 51.25 | 20.9
9.036 | 49.06 | 21.5 | 49.6 | 20.9 | 50.5 | 20.8
10.037 | 49.06 | 21.8 | 49.8 | 20.9 | 51.0 | 20.7
11.037 | 48.84 | 21.9 | 49.0 | 21.0 | 52.5 | 20.7
12.037 | 49.50000000000001 | 22.0 | 49.8 | 21.1 | 51.25 | 20.8
13.037 | 48.84 | 22.1 | 49.0 | 21.2 | 50.25 | 20.9
14.037 | 47.08 | 22.2 | 48.8 | 21.2 | 50.25 | 20.9
15.037 | 9.9 | 22.6 | 12.6 | 21.5 | 13.25 | 21.1
16.037 | -0.22000000000000003 | 23.2 | 0.2 | 22.2 | 0.25 | 21.7
17.037 | -1.1 | 23.3 | -1.8 | 22.4 | -2.25 | 21.9
18.037 | -35.64 | 22.7 | -38.0 | 21.7 | -38.75 | 21.3
19.037 | -49.720000000000006 | 22.0 | -55.0 | 21.2 | -53.0 | 20.9
20.037 | -51.04 | 21.8 | -54.8 | 21.1 | -52.5 | 20.9
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

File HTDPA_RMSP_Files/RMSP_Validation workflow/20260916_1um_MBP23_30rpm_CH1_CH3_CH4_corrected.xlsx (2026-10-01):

time_s | s1_flow_ml_min | s1_temp_c | s3_flow_ml_min | s3_temp_c | s4_flow_ml_min | s4_temp_c
0.005 | 0 | 24.8 | 0 | 24.3 | 0 | 23.6
1.005 | 0 | 24.9 | 0 | 24.4 | 0 | 23.6
2.005 | 0 | 24.9 | 0 | 24.5 | 0 | 23.7
3.005 | 0 | 25 | 0 | 24.5 | 0 | 23.7
4.005 | 0.44 | 24.9 | 0 | 24.5 | 0 | 23.7
5.036 | 0.66 | 24.5 | 1.8 | 24.3 | 1.75 | 23.5
6.036 | 23.1 | 23.6 | 25 | 22.8 | 29 | 22.2
7.036 | 52.58 | 21.7 | 53.4 | 21.3 | 53.5 | 21.1
8.036 | 49.5 | 21.4 | 50.6 | 21 | 51.25 | 20.9
9.036 | 49.06 | 21.5 | 49.6 | 20.9 | 50.5 | 20.8
10.037 | 49.06 | 21.8 | 49.8 | 20.9 | 51 | 20.7
11.037 | 48.84 | 21.9 | 49 | 21 | 52.5 | 20.7
12.037 | 49.5 | 22 | 49.8 | 21.1 | 51.25 | 20.8
13.037 | 48.84 | 22.1 | 49 | 21.2 | 50.25 | 20.9
14.037 | 47.08 | 22.2 | 48.8 | 21.2 | 50.25 | 20.9
15.037 | 9.9 | 22.6 | 12.6 | 21.5 | 13.25 | 21.1
16.037 | -0.22 | 23.2 | 0.2 | 22.2 | 0.25 | 21.7
17.037 | -1.1 | 23.3 | -1.8 | 22.4 | -2.25 | 21.9
18.037 | -35.64 | 22.7 | -38 | 21.7 | -38.75 | 21.3
19.037 | -49.72 | 22 | -55 | 21.2 | -53 | 20.9
20.037 | -51.04 | 21.8 | -54.8 | 21.1 | -52.5 | 20.9
21.037 | -51.04 | 21.6 | -55 | 21.1 | -52.75 | 20.9
22.037 | -51.04 | 21.6 | -55 | 21.1 | -52.5 | 20.9
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

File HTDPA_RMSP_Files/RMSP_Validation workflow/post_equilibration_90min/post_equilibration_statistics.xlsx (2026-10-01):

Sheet: channel_summary
channel | n_samples | n_cycles | temperature_mean_C | temperature_sd_C | temperature_cv_percent | Q_plus_mean | Q_plus_sd | Q_plus_cv_percent | Q_minus_mean | Q_minus_sd | Q_minus_cv_percent | P_to_P_mean | P_to_P_sd | P_to_P_cv_percent | symmetry_mean | symmetry_sd | symmetry_cv_percent | period_s_mean | period_s_sd | period_s_cv_percent
CH1 | 20761 | 848 | 29.10451327 | 0.6348921254 | 2.181421553 | 40.44582143 | 1.239587059 | 3.064808712 | -42.74885377 | 0.6362689037 | 1.48838822 | 83.1946752 | 1.63555935 | 1.965942347 | 0.946139419 | 0.0257857206 | 2.725361621 | 24.4525566 | 0.4971631771 | 2.033174629
CH3 | 20761 | 848 | 28.24980974 | 0.5801543607 | 2.053657586 | 43.81080076 | 0.5403142569 | 1.233290073 | -49.96987421 | 0.5800500041 | 1.160799408 | 93.78067498 | 1.090555622 | 1.162878837 | 0.8767497303 | 0.004837537981 | 0.5517581373 | 24.4525566 | 0.4971655518 | 2.033184341
CH4 | 20761 | 848 | 27.26204422 | 0.5140806769 | 1.885701134 | 43.36857276 | 0.9164697103 | 2.1132116 | -46.21911922 | 0.7579018485 | 1.639801583 | 89.58769198 | 1.648317166 | 1.839892433 | 0.9382737121 | 0.007498572327 | 0.7991881506 | 24.4525566 | 0.497902542 | 2.0361983
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

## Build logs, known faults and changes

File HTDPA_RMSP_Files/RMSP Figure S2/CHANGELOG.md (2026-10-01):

# Changelog

## 2026-09-30

- Rebuilt the Picture1-style A-E waveform, CV, temperature, and signal figure directly from the normalized XLSX workbook at 1200 dpi.

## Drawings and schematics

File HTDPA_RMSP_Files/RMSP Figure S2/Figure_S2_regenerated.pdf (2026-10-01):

A

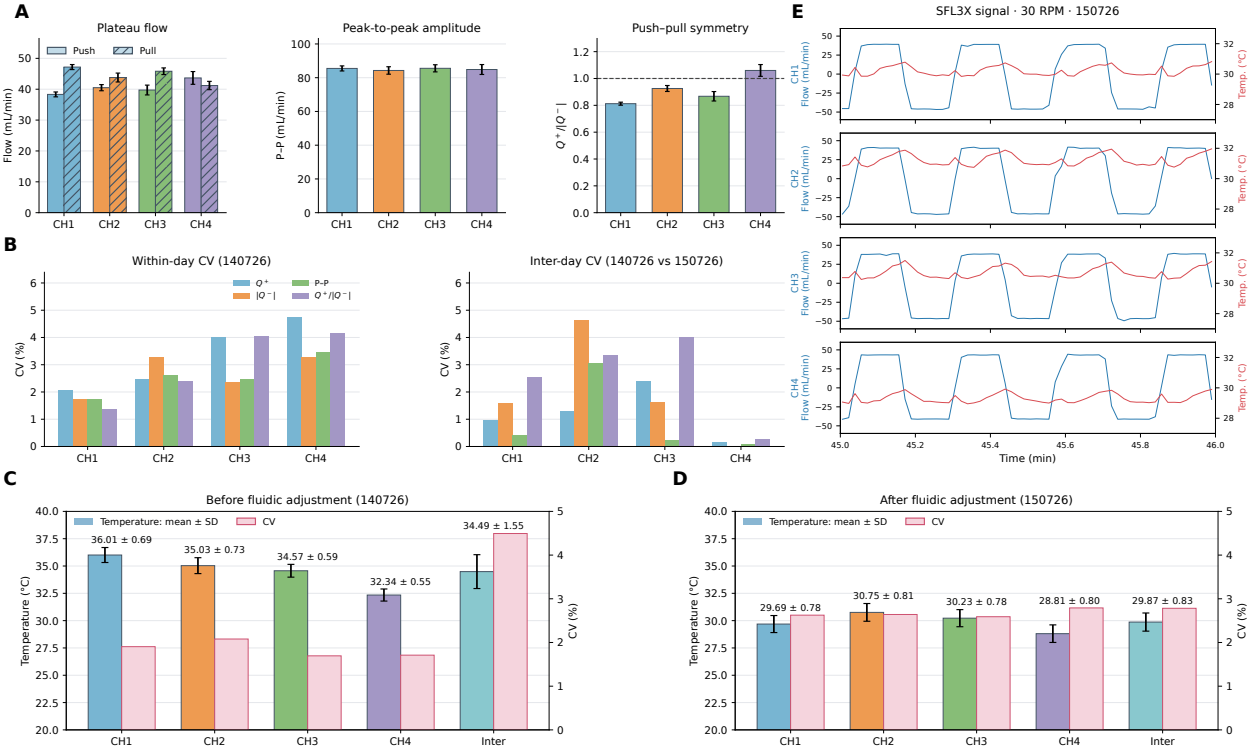
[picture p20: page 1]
Plateau flow; Push; Pull; P–P (mL/min); E SFL3X signal · 30 RPM · 150726; Temp. (°C); Time (min); Inter; Temperature (°C); Temperature: mean ± SD

Peak-to-peak amplitude

Push–pull symmetry

Flow (mL/min)

Within-day CV (140726)

Inter-day CV (140726 vs 150726)

Before fluidic adjustment (140726)

After fluidic adjustment (150726)

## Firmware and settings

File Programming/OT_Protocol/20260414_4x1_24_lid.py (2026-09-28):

from opentrons import protocol_api, types

# metadata
metadata = {
    "author": "Mahdi Rastegar - Modified for Release Experiment with Lid Handling",
    "apiLevel": "2.18"
}

# Protocol for Release Experiment (single apparatus) with automated lid handling
# 1- manually loadings at lower row at HTDA block
# 2- OT wait 5 minutes before starting from the moment we loaded sample manually
# 3- For every time point:
#      a. OT removes the lid from the wellplate (slot 3) and parks it on the lid holder (slot 6)
#      b. OT will take sample from upper row and transfer to Microplate 250 ul (all 4 cells)
#      c. OT removes the lid from the holder and places it back on the wellplate
#      d. OT replace media with 250 ul from reservoir to upper row
# 4- OT will repeat step 3 for 24 times with 12 minutes interval (using rows A-D for first 12, E-H for next 12)

# protocol run function
def run(protocol: protocol_api.ProtocolContext):

    # labware
    release_experiment_1 = protocol.load_labware("sdl5_4_channel_apparatus_12ul", location="4")

    tiprack_1 = protocol.load_labware("opentrons_96_tiprack_300ul", location="2")
    # tiprack_2 = protocol.load_labware("opentrons_96_tiprack_300ul", location="5")

    release_sample = protocol.load_labware("greiner_96_wellplate_382ul", location="3")
    release_media = protocol.load_labware("calab_8_tuberack_20000ul", location="7")

    # Lid holder for the sample wellplate's lid
    lid_holder = protocol.load_labware("greiner_96_wellplate_382ul", location="6")  # Assuming lid is stored/parked in a 96-well plate format for simplicity

    # Denote an empty slot as a 1000 uL tiprack - used as a "fake" tip so the lid tool can grip/release the lid
    tiprack_fake = protocol.load_labware("opentrons_lid_tiprack_1000ul", location="11")

    # pipettes
    p300 = protocol.load_instrument("p300_single", mount="left", tip_racks=[tiprack_1])
    # p300 = protocol.load_instrument("p300_single", mount="left", tip_racks=[tiprack_1, tiprack_2])

    # Right pipette: mechanical lid handling via pick_up_tip/drop_tip at calibrated points.
    lid_tool = protocol.load_instrument("p1000_single", mount="right")

    # experiment setup
    sample_volume = 250  # volume to transfer from upper row to microplate
    media_volume = 250   # volume to replace in upper row from reservoir
    p300.flow_rate.aspirate = 50
    p300.flow_rate.dispense = 50

    # Lid holder and plate are treated like a 96-well grid; D6 + XY offset hits physical lid center.
    lid_center_well = "D6"
    lid_center_xy_offset = (0, 0)
    lid_center_z_offset = 20
    # Grip (pick up) depth is confirmed working. Release depth is separately tunable:
    # a friction/collet fit often needs to be pushed measurably deeper to let go than
    # to seat. If release still doesn't drop the lid, jog deeper in ~2-5mm increments.
    lid_grip_depth = 18.8
    lid_release_depth = 18.8

    def take_sample_from_upper_row(sample_volume, time_point):
        """Take sample from upper row (row A) and transfer to microplate"""
        p300.well_bottom_clearance.dispense = 5
        p300.well_bottom_clearance.aspirate = 2

        # Each apparatus cell goes to its corresponding wellplate rows, different columns for each time point
        # Time points 0-11: use rows A,B,C,D; Time points 12-23: use rows E,F,G,H
        if time_point < 12:
            microplate_rows = ['A', 'B', 'C', 'D']
            column_number = time_point + 1  # Columns 1-12 for first set
        else:
            microplate_rows = ['E', 'F', 'G', 'H']
            column_number = (time_point - 12) + 1  # Columns 1-12 for second set

        for n in range(4):  # 4 wells A1-A4 from apparatus
            p300.pick_up_tip()
            from_well = 'A' + str(n+1)  # Upper row wells A1, A2, A3, A4 from apparatus
            target_row = microplate_rows[n]  # A1→A, A2→B, A3→C, A4→D
            to_well = target_row + str(column_number)  # A1-A12,B1-B12,C1-C12,D1-D12, then E1-E12,F1-F12,G1-G12,H1-H12
            p300.transfer(
                sample_volume,
                release_experiment_1[from_well],
                release_sample[to_well],
                blow_out=True,
                blowout_location='destination well',
                new_tip='never'
            )
            p300.return_tip()

    def replace_media_in_upper_row(media_volume):
        """Replace media with 250 ul from reservoir to upper row"""
        p300.well_bottom_clearance.dispense = 3
        p300.well_bottom_clearance.aspirate = 3

        for n in range(4):  # 4 wells A1-A4
            p300.pick_up_tip()
            from_well = 'A' + str(n+1)  # Reservoir wells A1, A2, A3, A4
            to_well = 'A' + str(n+1)    # Upper row wells A1, A2, A3, A4
            p300.transfer(
                media_volume,
                release_media[from_well],
                release_experiment_1[to_well],
                blow_out=True,
                blowout_location='destination well',
                new_tip='never'
            )
            p300.return_tip()

    def lid_top_with_xy_offset(target_well, z_height, xy_offset):
        # Build a centered lid contact location from nominal well top + calibrated XY shift.
        return target_well.top(z=z_height).move(types.Point(x=xy_offset[0], y=xy_offset[1], z=0))

    def custom_lid_approach(instr, target_well, z_offset=lid_center_z_offset, approach_z=8, lid_depth=lid_grip_depth, xy_offset=(5.0, -5.0), dwell=0.5):
        # Mimics the old custom sequence: approach above lid, descend to grip/release depth, retract.
        instr.move_to(lid_top_with_xy_offset(target_well, z_offset + approach_z, xy_offset))
        protocol.delay(seconds=dwell)
        instr.move_to(lid_top_with_xy_offset(target_well, z_offset - lid_depth, xy_offset))
        protocol.delay(seconds=dwell)
        instr.move_to(lid_top_with_xy_offset(target_well, z_offset, xy_offset))
        protocol.delay(seconds=dwell)

    def remove_lid_from_wellplate():
        """Move the lid from the sample wellplate (slot 3) onto the lid holder (slot 6)"""
        plate_center = release_sample[lid_center_well]
        holder_well = lid_holder[lid_center_well]

        # 1. Pick up the well plate lid with the motion to physically pick up the lid (microplate)
        custom_lid_approach(lid_tool, plate_center, z_offset=lid_center_z_offset, lid_depth=lid_grip_depth, xy_offset=lid_center_xy_offset)
        lid_tool.move_to(lid_top_with_xy_offset(plate_center, lid_center_z_offset - 60, lid_center_xy_offset))

        # 2. Pick up an "imaginary" pipette tip to tell the OT2 it has a tip (which is actually our lid)
        lid_tool.pick_up_tip(location=tiprack_fake["D6"])  # pick up from the middle to minimize chances for collision
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

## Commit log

2026-09-28 Add requirements file for HTDPA Dashboard with essential libraries
    [P23-CAF-10-28-30RPM.xlsx, P23-DCF-10-28-30RPM.xlsx, P23-NAPX-10-28-30RPM.xlsx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]
2026-09-28 Add new well plate configurations for SDL5 apparatus
    - Created sdl5_4_channel_apparatus_12ul.json for a 4-channel apparatus with 12µL wells.
    - Added sdl5_4_channel_apparatus_12ul_90degree.json for a 90-degree variant of the 4-channel apparatus.
    - Introduced sdl_8_wellplate_8000ul.json for an 8-well plate with a total volume of 8000µL.
    [wellplate_lid.STL, wellplate_lid_1.SLDPRT, wellplate_lid_2.SLDPRT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]
2026-09-28 Add requirements file for HTDPA dashboard UI dependencies
    [HTDA_4C.STL, RMSP - OT-2 Reference Model Updated-1 Stripped __-1 Reciprocating PUmp-1 Act_housing_V2-1.STL, RMSP - OT-2 Reference Model Updated-1 Stripped __Mo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]
2026-09-30 Add transient 2D CFD simulation for reciprocating flow in a rectangular chamber
    - Implemented a new simulation script `warp_reciprocating_flow.py` using NVIDIA Warp's FEM module.
    - Defined geometry and physics parameters for the flow simulation, including rectangular chamber dimensions and flow characteristics.
    - Developed a simulation class to handle grid setup, boundary conditions, and time-stepping.
    - Included functions for calculating velocity profiles, mass and inertia forms, and vorticity.
    - Added functionality to save simulation results and perform parameter sweeps for flow rate amplitudes.
2026-10-01 creat htdpa lid.stl
    [HTDPA_Lid.STL]
